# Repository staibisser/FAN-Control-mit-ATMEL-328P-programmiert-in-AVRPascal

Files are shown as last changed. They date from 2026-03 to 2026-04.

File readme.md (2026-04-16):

# FAN-Control – Lüfter- und Schiebersteuerung

> Kompakte Embedded-Steuerung für Lüfter und Abgasschieber eines Gasdurchlauferhitzers,
> entwickelt mit eigener Hardware in **KiCad** und Firmware in **AVRPascal** auf einem **ATmega328PB**.

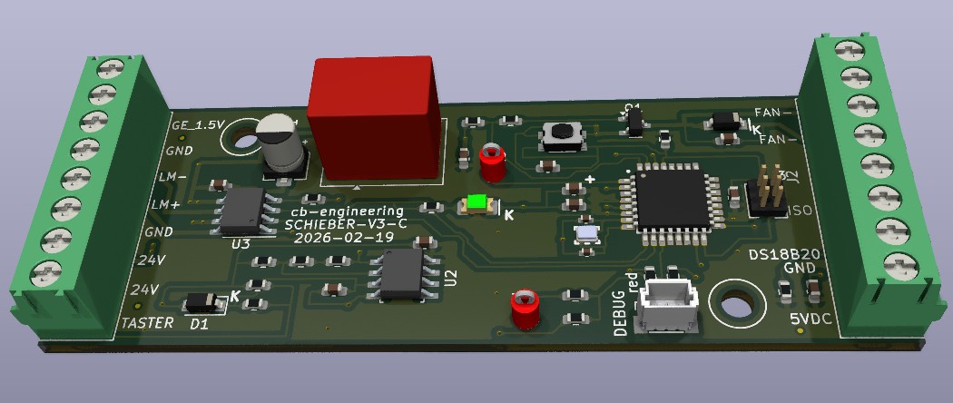
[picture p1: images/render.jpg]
PCB Render


---

## Überblick

**FAN-Control** überwacht den Betriebszustand eines Gasdurchlauferhitzers und steuert automatisch:

- den **Abgasschieber** (motorisch, via H-Brücke) – öffnet beim Einschalten des Geräts
- den **Lüfter** – schaltet temperaturabhängig zu

Die Steuerung erkennt den Gerätezustand über ein **Analogsignal**, misst die **Abgastemperatur** mit einem DS18B20-Sensor und reagiert zusätzlich auf einen **manuellen Taster**.

---

## Systemarchitektur

```
24 V DC
   │
   ▼
Spannungsaufbereitung
   │
   ▼
ATmega328PB (PD2–PD7)
   ├── PD3 ◄── LM358 (Analogsignal Gerätezustand)
   ├── PD4 ◄── DS18B20 (1-Wire Temperatursensor)
   ├── PD7 ◄── Taster (manuell Ein/Aus)
   ├── PD5/PD6 ──► DRV8871DDA (H-Brücke → Schieber-Motor)
   └── PD2 ──► AO3400A (MOSFET → Lüfter)
```

---

## Hardware

### Hauptkomponenten

| Bauteil | Bezeichnung | Funktion |
|---|---|---|
| Mikrocontroller | ATmega328PB | Zentrale Steuerlogik |
| Temperatursensor | DS18B20 | 1-Wire Temperaturmessung |
| Motortreiber | DRV8871DDA | H-Brücke für Schieber-Motor |
| Lüftertreiber | AO3400A | N-Kanal MOSFET zum Schalten des Lüfters |
| Signalaufbereitung  | LM358 | Operationsverstärker für Geräte-Signal |
| Versorgung | 24 V DC | Externe Versorgungsspannung |
| Gehäuse | Bernic Series 350 | DIN-Schienenmontage |

### Gehäuse

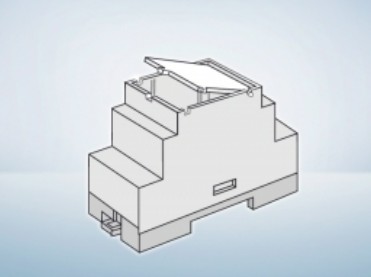
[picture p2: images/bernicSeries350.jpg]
Bernic Series 350


### Pin-Belegung (ATmega328PB)

| Pin  | Port | Richtung | Funktion |
|---|---|---|---|
| PD2  | D2 | OUTPUT | Lüfter Ein/Aus (via AO3400A MOSFET) |
| PD3  | D3 | INPUT | Betriebssignal Durchlauferhitzer (via LM358)|
| PD4  | D4 | I/O | DS18B20 1-Wire Datenleitung |
| PD5  | D5 | OUTPUT | DRV8871 IN1 – Motor Auf |
| PD6  | D6 | OUTPUT | DRV8871 IN2 – Motor Zu |
| PD7  | D7 | INPUT | Taster – manuell Schieber Ein/Aus |

---

## Firmware

### Zustandslogik

Die Haupt-Schlaufe läuft kontinuierlich mit einer Pause von **250 ms** pro Zyklus.

```
┌─────────────────────────────────────────────────┐
<<<<<<< Updated upstream
│  Einschalten (SchieberOnOff = TRUE) wenn:       │
│    GEon = 1  (Durchlauferhitzer läuft)          │
│    OR  Temperatur > 40 °C                       │
│    OR  Taster aktiv                             │
├─────────────────────────────────────────────────┤
│  Ausschalten (SchieberOnOff = FALSE) wenn:      │
│    GEon = 0  AND  Temperatur ≤ 40 °C            │
│    AND  Taster nicht aktiv                      │
=======
│  Einschalten (SchieberOnOff = TRUE) wenn:        │
│    GEon = 1  (Durchlauferhitzer läuft)           │
│    OR  Temperatur > 40 °C                        │
│    OR  Taster aktiv                              │
├─────────────────────────────────────────────────┤
│  Ausschalten (SchieberOnOff = FALSE) wenn:       │
│    GEon = 0  AND  Temperatur ≤ 40 °C            │
│    AND  Taster nicht aktiv                       │
>>>>>>> Stashed changes
└─────────────────────────────────────────────────┘
```

**Temperatur-Schwellwert:** `TempFan = 40 °C` (konfigurierbar als Konstante im Quellcode)

**Fehlertoleranz:** Bei einem Lesefehler des DS18B20 (`seCRCError`, `seNoSensor`) bleibt der zuletzt gültige Temperaturwert (`lastGoodTemp`) erhalten.

### Motor-Ansteuerung

Der DRV8871-Motortreiber wird über zwei Ausgänge angesteuert:

| Befehl | IN1 | IN2 | Lüfter |
|---|-----|-----|---|
| Schieber AUF | HIGH | LOW | EIN |
| Schieber ZU  | LOW | HIGH | AUS |

Zwischen den Schaltzuständen werden kurze Mikrosekunden-Pausen eingehalten, um Stromspitzen zu vermeiden.

### DS18B20 – Eigene 1-Wire Implementierung

Der Sensor wird über **direktes Port-Bit-Banging** (DDRD / PORTD / PIND) ohne externe Bibliothek angesprochen. Die Implementierung beinhaltet:

- 1-Wire Reset mit Präsenzsignal-Erkennung
- Bit-genaues Read/Write mit µs-Timing
- **CRC8 Dallas-Prüfsumme** zur Datenvalidierung
- Fehlerbehandlung über den Typ `TSensorError`:

| Fehlercode | Bedeutung |
|---|---|
| `seNone` | Kein Fehler |
| `seNoSensor` | Sensor nicht erkannt (kein Präsenzsignal) |
| `seCRCError` | Prüfsummenfehler |
| `seOutOfRange` | Temperaturwert ausserhalb −55…+125 °C |

---

## Projektstruktur

```
FAN-Control-mit-ATMEL-328P-programmiert-in-AVRPascal/
├── Hardware/
│   ├── 700000008-SCHIEBER-V3.kicad_sch   # Schaltplan
│   ├── 700000008-SCHIEBER-V3.kicad_pcb   # PCB-Layout
│   └── 700000008-SCHIEBER-V3.kicad_pro   # KiCad Projektdatei
│
├── Software/
│   ├── P_700000008_V3_A.pas              # Hauptprogramm
│   ├── DS18B20.pas                       # 1-Wire Sensor Unit
<<<<<<< Updated upstream
│   ├── testDS18B20.pas                   # 1-Wire Sensor Test mit Ausgabe an UART
=======
│   ├── P_700000008_V3_A.hex              # Flash-fertige Hex-Datei
│   ├── P_700000008_V3_A.elf              # ELF Debug-Binary
│   └── P_700000008_V3_A.bin              # Rohes Binärimage
>>>>>>> Stashed changes
│
├── images/
│   ├── render.jpg                        # PCB 3D-Render
│   └── bernicSeries350.jpg               # Gehäuse DIN-Schiene
│
├── LICENSE
└── readme.md
```

---

## Voraussetzungen

### Hardware

- Zielhardware mit **ATmega328PB**
- 24 V DC Versorgung
- DS18B20 Temperatursensor
- Abgasschieber mit geeignetem DC-Motor
- Lüfter
- Programmer: **USBasp** oder kompatibel

### Software

- [AVRPascal / Free Pascal AVR Toolchain](https://www.freepascal.org/)
- [avrdude](https://github.com/avrdudes/avrdude) zum Flashen
- [KiCad](https://www.kicad.org/) für Änderungen an der Hardware

---

## Build & Flash

### Flashen (fertige Hex-Datei)

```bash
avrdude -c usbasp -p m328pb -P usb -U flash:w:Software/P_700000008_V3_A.hex
```

> **Hinweis:** Den Partcode `-p m328pb` verwenden (nicht `m328p`), da es sich um den **ATmega328PB** handelt.

### Fuse-Konfiguration

Die Fuse-Bits müssen zur Taktquelle passen:

| Fuse | Empfehlung |
|---|---|
| CKSEL  | Externer 16 MHz Quarz |
| CKDIV8 | Deaktiviert (kein Vorteiler) |
| BODLEVEL | Je nach Anwendung (empfohlen: 2,7 V) |

Beispiel (externer 16 MHz Quarz, BOD 2,7 V):

```bash
avrdude -c usbasp -p m328pb -P usb \
  -U lfuse:w:0xFF:m \
  -U hfuse:w:0xD9:m \
  -U efuse:w:0xFF:m
```

> ⚠️ Falsche Fuse-Einstellungen können den Mikrocontroller scheinbar unbrauchbar machen. Vor dem Setzen unbedingt mit dem Datenblatt abgleichen.

---

## Projektstatus

| Bereich | Status |
|---|---|
| Hardware | ✅ Entwickelt |
| Firmware | ✅ Lauffähig |
| Taktquelle | ✅ Externer 16 MHz Quarz getestet |
| Flash-Prozess | ✅ USBasp / avrdude erfolgreich |
| Feldbetrieb  | 🔄 In Erprobung |

---

## Mögliche Erweiterungen

- Serielle Diagnoseausgabe (UART) für Temperatur- und Zustandslogs
- Fehlererkennung mit Status-LED oder Summerton
- Parametrierung von `TempFan` über Taster oder EEPROM
- Watchdog-Timer für erhöhte Ausfallsicherheit
- Stückliste (BOM) als PDF oder CSV

---

## Sicherheitshinweis

Dieses Projekt ist **kein zertifiziertes Sicherheitsprodukt** und **kein freigegebenes Seriengerät**.
Der Einsatz erfolgt ausschliesslich auf eigene Verantwortung – insbesondere bei Anwendungen mit
Gasgeräten, Wärmequellen oder beweglichen Aktoren. Vor dem Praxiseinsatz müssen alle
elektrischen, thermischen und sicherheitstechnischen Aspekte eigenständig geprüft werden.

---

## Lizenz

MIT License – siehe [LICENSE](LICENSE)

---

<<<<<<< Updated upstream
=======
## Autor

**Christof Biner** ([@staibisser](https://github.com/staibisser))
>>>>>>> Stashed changes

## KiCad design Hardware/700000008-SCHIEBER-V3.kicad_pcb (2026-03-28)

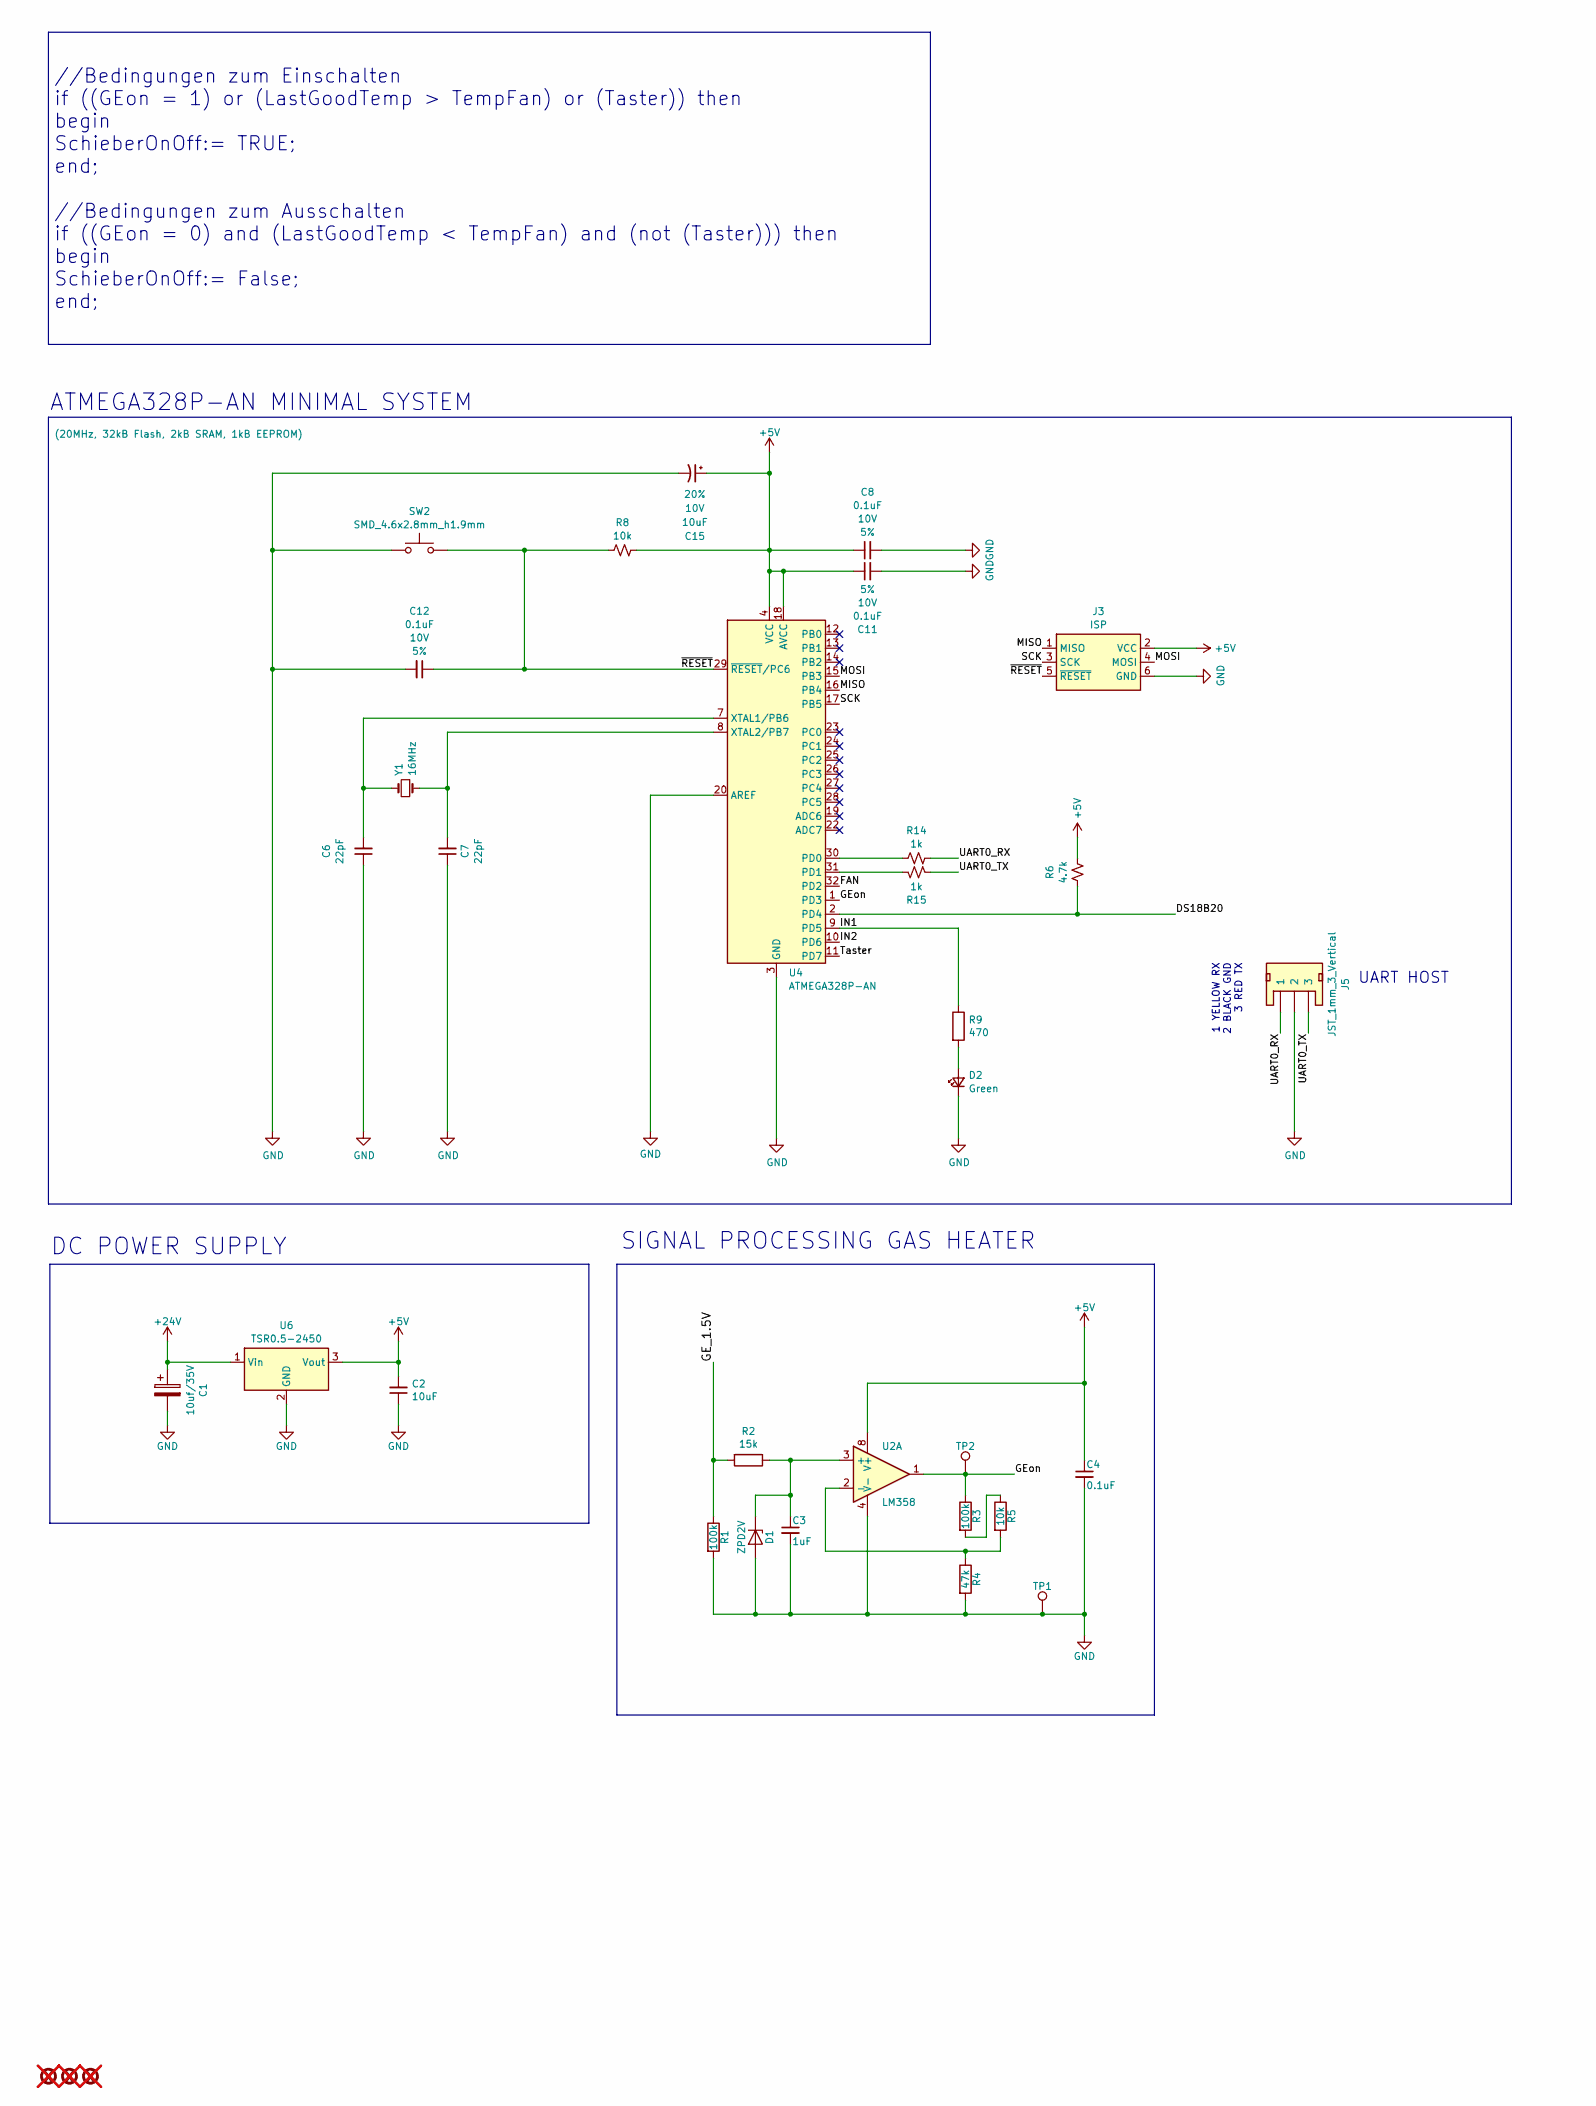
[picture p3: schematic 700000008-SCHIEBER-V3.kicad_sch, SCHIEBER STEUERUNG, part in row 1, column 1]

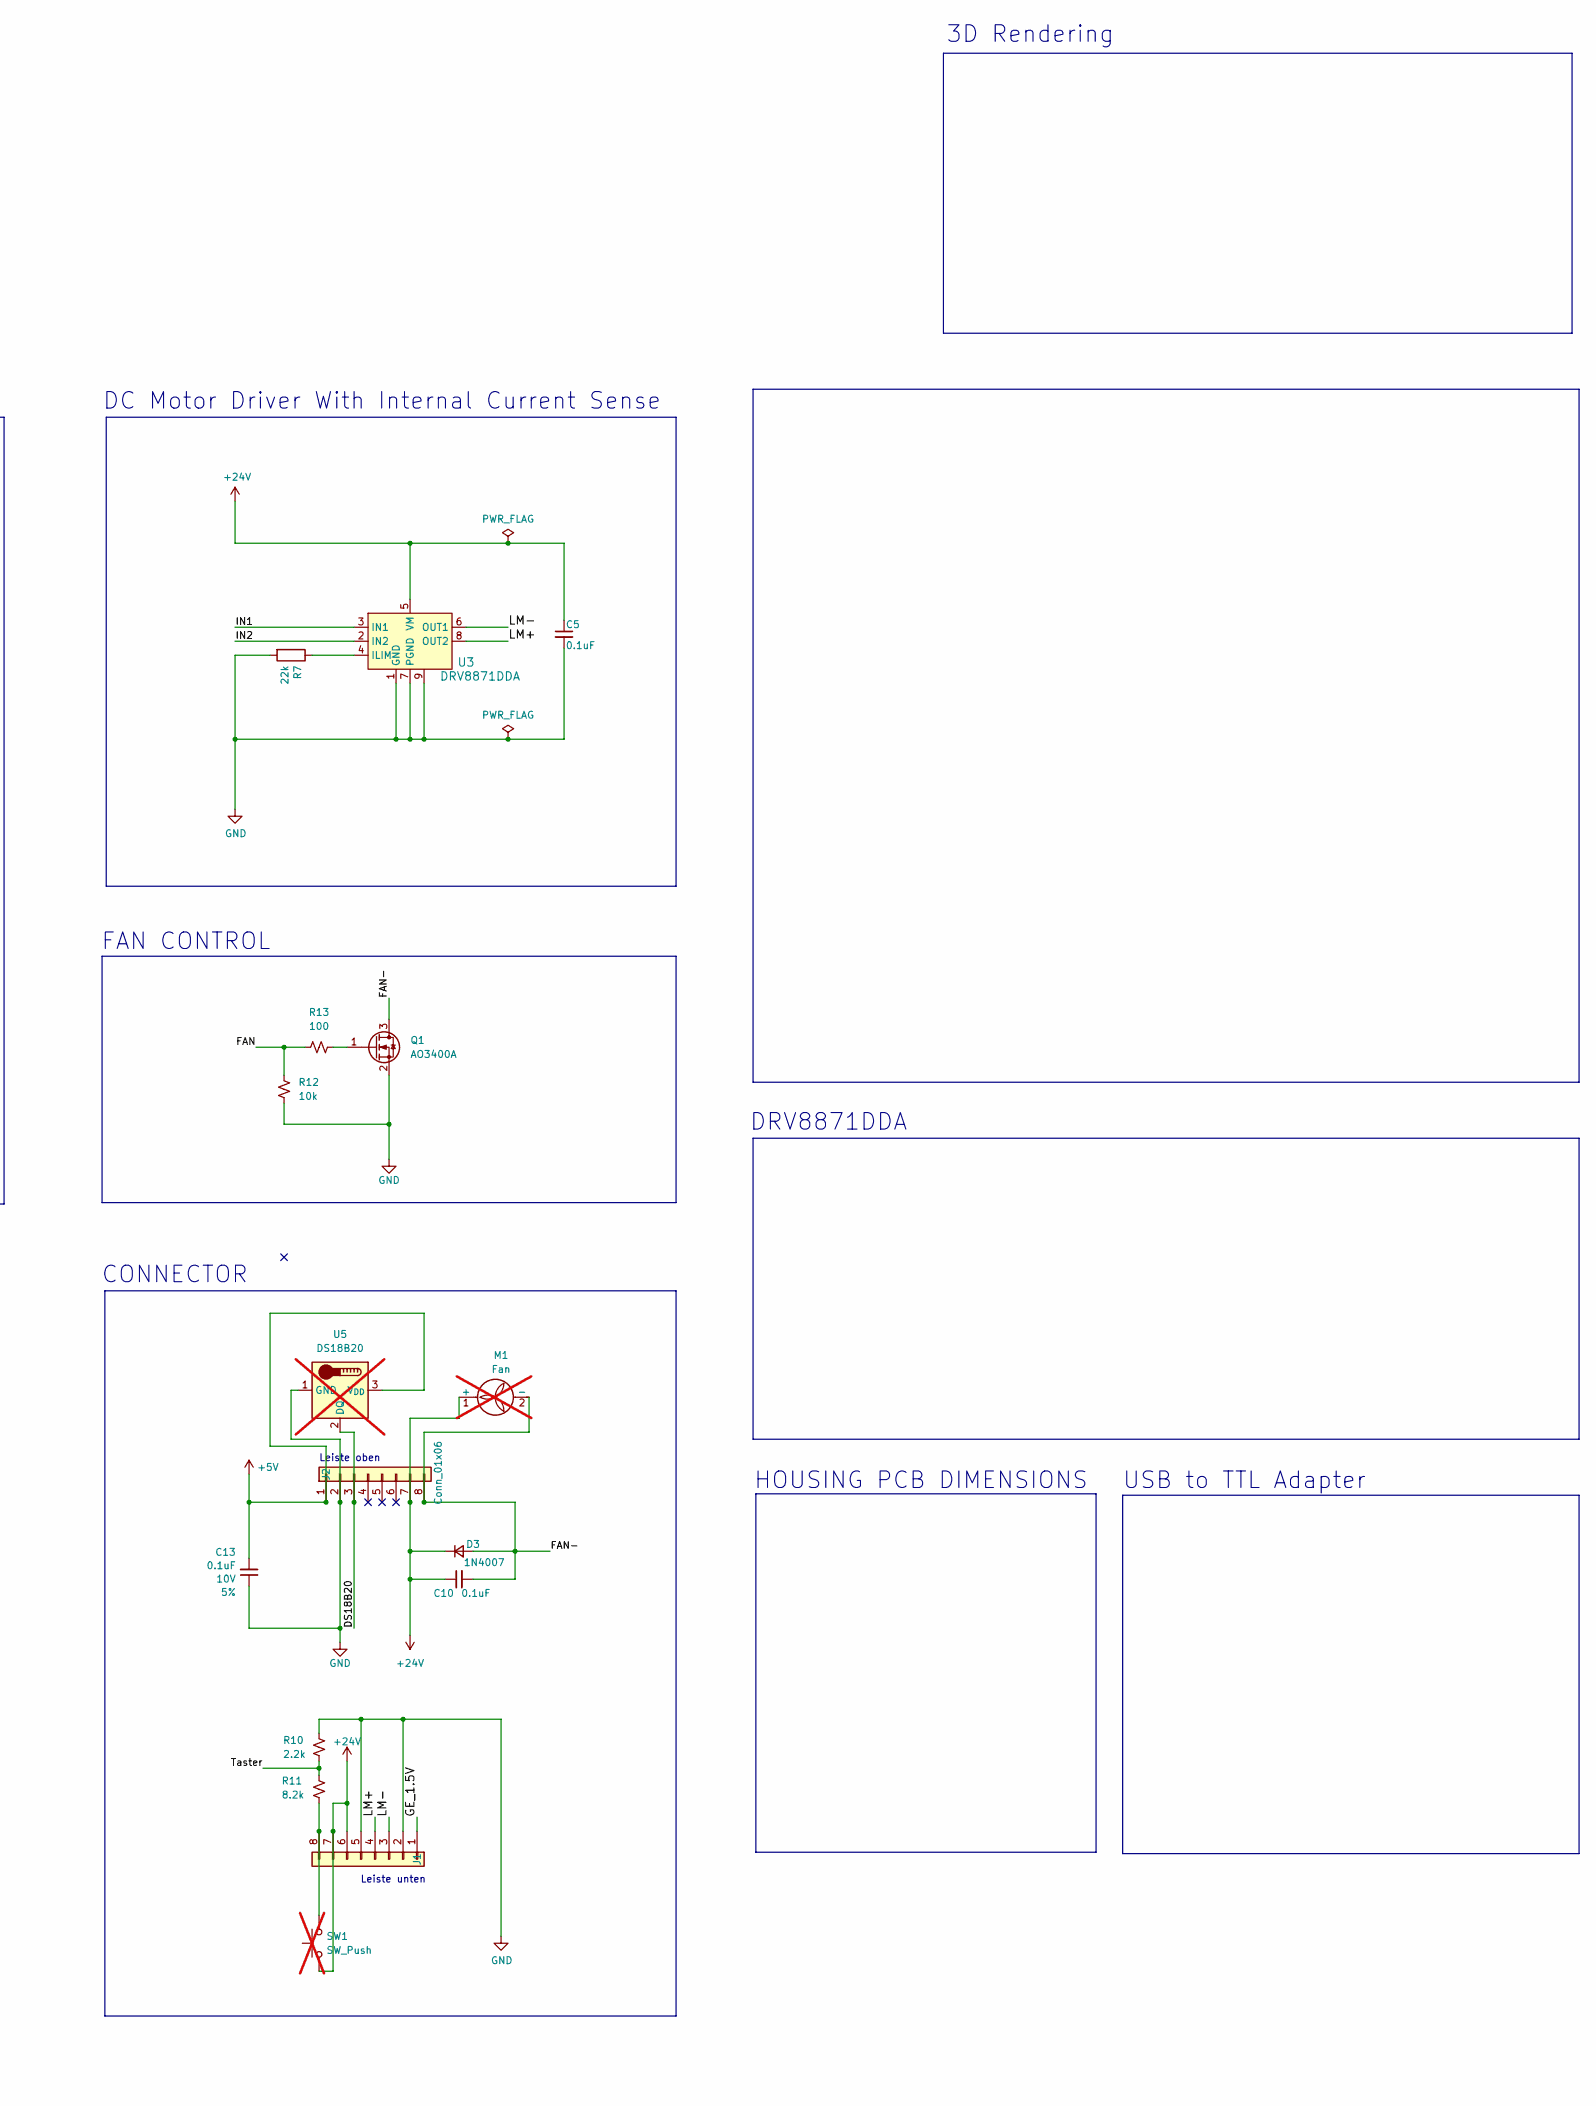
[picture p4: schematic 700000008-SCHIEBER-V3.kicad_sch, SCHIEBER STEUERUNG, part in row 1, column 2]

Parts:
C1: 10uf/35V; CP_Elec_4x5.8; Tolerance 20%; Voltage 35V; MPN EXV106M035A9DAA; Digikey EXV106M016S9BAA
C2: 10uF; C_0603_1608Metric; Tolerance 20%; Voltage 10V
C3: 1uF; C_0603_1608Metric; Tolerance 5%
C4, C5: 0.1uF; C_0603_1608Metric; Tolerance 5%; Voltage 10V
C6, C7: 22pF; C_0402_1005Metric; Voltage 10V; Tolerance 5%
C8, C10, C11, C12, C13: 0.1uF; C_0603_1608Metric; Voltage 10V; Tolerance 5%
C15: 10uF; C_0603_1608Metric; Voltage 10V; Tolerance 20%
D1: ZPD2V; D_SOD-123; MPN BZT52C2V0-7-F; Digikey BZT52C2V0-7-F
D2: Green; LED_1206_3216Metric_Green; MPN IN-S126ATG; Digikey IN-S126ATG
D3: 1N4007; SOD-123; Voltage 1000V; MPN 1N4007W; Digikey 1N4007W
FID1, FID2, FID3: Fiducial_0.5mm; Fiducial_0.5mm_Mask1mm; not fitted
J1, J2: Conn_01x06; TerminalBlock_Phoenix_PT-1,5-8-3.5-H_1x08_P3.50mm_Horizontal; MPN 1751303; Digikey 1751303
J3: ISP; PinHeader_2x03_P1.27mm_Vertical; MPN 20021111-00006T1LF
J5: JST_1mm_3_Vertical; JST_1x03_P1.0mm_Vertical_SMD; MPN BM03B-SRSS-TB
M1: Fan; not fitted
Q1: AO3400A; SOT-23; MPN AO3400A
R1, R3: 100k; R_0603_1608Metric; Tolerance 5%
R2: 15k; R_0603_1608Metric; Tolerance 5%
R4: 47k; R_0603_1608Metric; Tolerance 5%
R5, R8, R12: 10k; R_0603_1608Metric; Tolerance 5%
R6: 4.7k; R_0603_1608Metric; Tolerance 5%
R7: 22k; R_0603_1608Metric; Tolerance 5%
R9: 470; R_0603_1608Metric; Tolerance 5%
R10: 2.2k; R_0603_1608Metric; Tolerance 5%
R11: 8.2k; R_0603_1608Metric; Tolerance 5%
R13: 100; R_0603_1608Metric; Tolerance 5%
R14, R15: 1k; R_0603_1608Metric; Tolerance 5%
SW1: SW_Push; not fitted
SW2: SMD_4.6x2.8mm_h1.9mm; Push_SMD_4.6x2.8mm_h1.9mm; MPN KMR221GLFS; Digikey CKN10259CT-ND
TP1, TP2: 1.0mm; TestPoint_THTPad_D2.0mm_Drill1.0mm; MPN 5000; Digikey 36-5000-ND
U2: LM358; SOIC-8_W3.9mm; MPN LM358DT; Digikey 497-1591-1-ND
U3: DRV8871DDA; SOIC-8-1EP_3.9x4.9mm_P1.27mm_EP2.41x3.81mm_ThermalVias; MPN DRV8871DDA; Digikey 296-44509-5-ND
U4: ATMEGA328P-AN; TQFP-32_7x7mm_P0.8mm; MPN ATMEGA328P-AN
U5: DS18B20; TO-92_Inline; not fitted
U6: TSR0.5-2450; Converter_DCDC_TRACO_TSR0.5-24xx_TSR0.5-24xxx_THT; MPN TSR 0.5-2450; Digi-Key_PN 1951-TSR0.5-2450-ND
Y1: 16MHz; Crystal_SMD_2.0x1.6mm; MPN XRCGB16M000FXN01R0

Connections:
+5V: C2.2, C4.1, C8.1, C11.1, C13.2, C15.1, J2.1, J3.2 (VCC), R6.2, R8.2, U2.8 (V+), U4.4 (VCC), U4.6 (VCC), U4.18 (AVCC), U5.3 (V_{DD}), U6.3 (Vout)
+24V: C1.1, C5.1, C10.1, D3.1 (K), J1.6, J1.7, J2.7, M1.1 (+), SW1.1, U3.5 (VM), U6.1 (Vin)
/DS18B20: J2.3, R6.1, U4.2 (PD4), U5.2 (DQ)
/FAN: R12.1, R13.1, U4.32 (PD2)
/FAN-: C10.2, D3.2 (A), J2.8, M1.2 (-), Q1.3 (D)
/GE_1.5V: J1.1, R1.1, R2.2
/GEon: R3.1, TP2.1, U2.1, U4.1 (PD3)
/IN1: R9.1, U3.3 (IN1), U4.9 (PD5)
/IN2: U3.2 (IN2), U4.10 (PD6)
/LM+: J1.4, U3.8 (OUT2)
/LM-: J1.3, U3.6 (OUT1)
/MISO: J3.1 (MISO), U4.16 (PB4)
/MOSI: J3.4 (MOSI), U4.15 (PB3)
/SCK: J3.3 (SCK), U4.17 (PB5)
/Taster: R10.1, R11.2, U4.11 (PD7)
/UART0_RX: J5.1, R14.2
/UART0_TX: J5.3, R15.2
/~RESET: C12.1, J3.5 (~RESET), R8.1, SW2.2, U4.29 (~RESET/PC6)
GND: C1.2, C2.1, C3.2, C4.2, C5.2, C6.1, C7.1, C8.2, C11.2, C12.2, C13.1, C15.2, D1.2 (A), D2.1 (K), J1.2, J1.5, J2.2, J3.6 (GND), J5.2, Q1.2 (S), R1.2, R4.2, R7.2, R10.2, R12.2, SW2.1, TP1.1, U2.4 (V-), U3.1 (GND), U3.7 (PGND), U3.9, U4.3 (GND), U4.5 (GND), U4.20 (AREF), U4.21 (GND), U5.1 (GND), U6.2 (GND)
unnamed: C3.1, D1.1 (K), R2.1, U2.3 (+)
unnamed: D2.2 (A), R9.2
unnamed: J1.8, R11.1, SW1.2
unnamed: Q1.1 (G), R13.2
unnamed: R3.2, R5.1
unnamed: R4.1, R5.2, U2.2 (-)
unnamed: R7.1, U3.4 (ILIM)
unnamed: R14.1, U4.30 (PD0)
unnamed: R15.1, U4.31 (PD1)
unnamed: C6.2, U4.7 (XTAL1/PB6), Y1.2
unnamed: C7.2, U4.8 (XTAL2/PB7), Y1.1

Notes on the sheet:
CONNECTOR
ATMEGA328P-AN MINIMAL SYSTEM
USB to TTL Adapter
UART HOST
1 YELLOW RX 2 BLACK GND 3 RED TX
DRV8871DDA
3D Rendering
DC POWER SUPPLY
FAN CONTROL
HOUSING PCB DIMENSIONS
Leiste oben
Leiste unten
SIGNAL PROCESSING GAS HEATER
DC Motor Driver With Internal Current Sense
//Bedingungen zum Einschalten if ((GEon = 1) or (LastGoodTemp > TempFan) or (Taster)) then begin SchieberOnOff:= TRUE; end; //Bedingungen zum Ausschalten if ((GEon = 0) and (LastGoodTemp < TempFan) and (not (Taster))) then begin SchieberOnOff:= False; end;

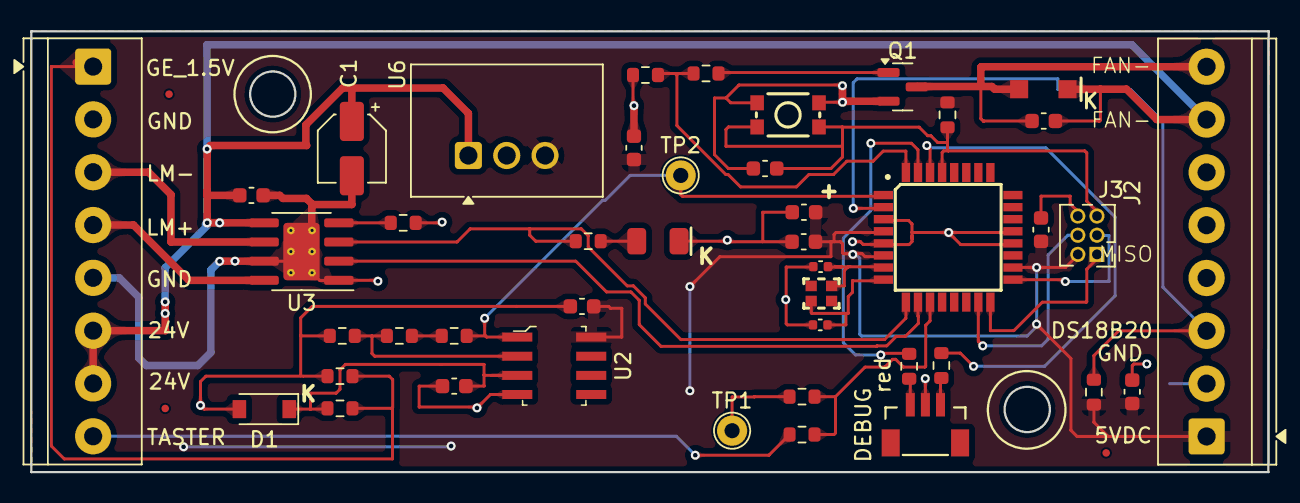
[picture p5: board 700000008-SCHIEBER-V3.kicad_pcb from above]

Board: 2 copper layers, 82.0 x 29.2 mm, 47 parts (0 on the bottom side), 30 nets.

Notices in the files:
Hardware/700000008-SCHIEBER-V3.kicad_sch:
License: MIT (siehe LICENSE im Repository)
